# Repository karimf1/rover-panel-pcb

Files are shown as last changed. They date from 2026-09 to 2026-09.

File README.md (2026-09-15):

# rover-panel-pcb 

The PCB was missing. It sits on
four standoffs on the panel plate, between the shunt and the signal
connector, and does three jobs:

- **precharge** — it switches the pack through the panel's 22 Ω resistor `R1`
  into the ESC bank, and holds contactor `K1` open until the switched bus
  reaches ~90 % of the pack
- **interlock** — `K1`'s coil is energised through the E-stop loop *and* this
  board, so the board can open `K1` but nothing on it can close `K1` past an
  open E-stop
- **current sense** — an INA228 on the panel's 0.75 mΩ shunt `RS1`, reported
  over I2C

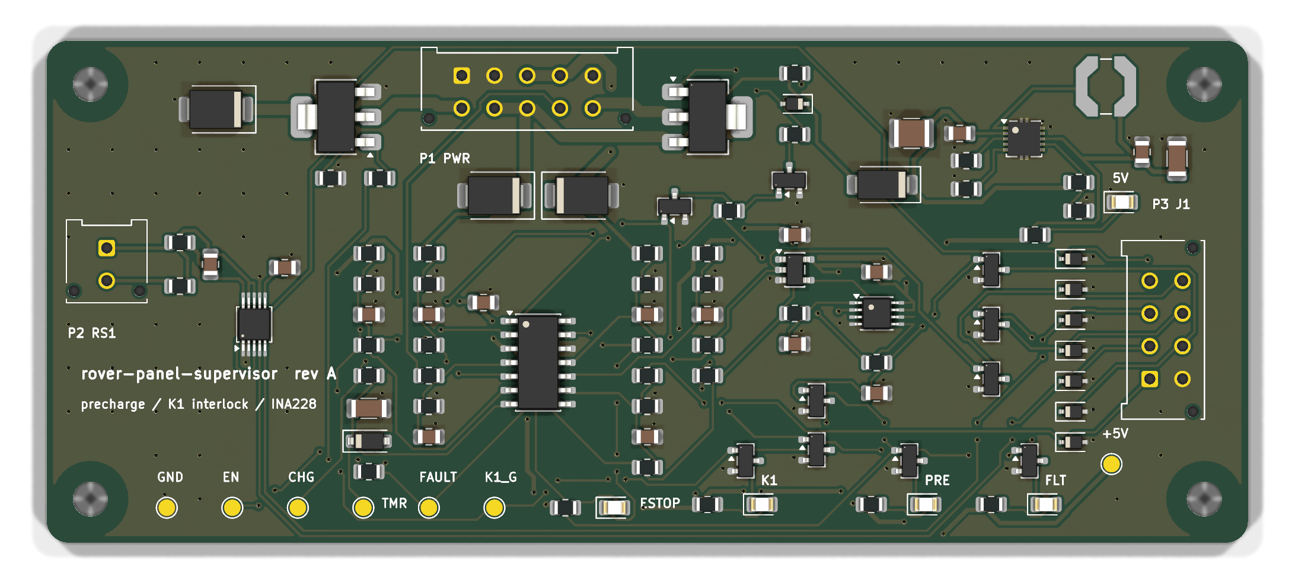
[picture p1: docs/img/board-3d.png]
Board


It replaces two of the panel's bought parts — `K2`, an automotive precharge
relay, and `A1`, an INA228 breakout on standoffs — and it answers two of the
panel's open questions: *"precharge is sized by hand and is not in any check"*
and *"is the E-stop hard-wired in series with the contactor coil?"*

The one claim the board is built to prove:

> **K1 cannot close unless the E-stop loop is closed AND the host has raised a
> fresh ARM edge AND the switched bus has reached the precharge threshold** —
> and that is hardware, checked against the exported netlist, not a promise
> made by firmware. There is no firmware.

---

## 1. How the interlock works

The logic is four comparators, one AND gate and one D flip-flop. Every node
that feeds the interlock is an open-collector output pulled up **to EN, not to
5 V** — so the instant the board disarms, every one of them falls with it.

| signal | made by | means |
|---|---|---|
| `ESTOP_OK` | U3C: the *far* side of the E-stop loop (`COIL_POS`) above 13.7 V | the mushroom switch is closed |
| `ARM` | U3D: host line above 1.37 V, 100 k pull-down | the host asked; an unplugged harness reads as *no* |
| `CLR#` | U4: `ARM AND ESTOP_OK` | either one dropping clears the latch immediately |
| `EN` | U5 (74LVC1G74) Q, set only on a **rising edge** of `ARM` delayed 10 ms | armed |
| `CHG` | U3A: switched bus / always-on bus **below** the threshold | precharging |
| `FAULT` | U3B: `CHG` has been high longer than the timer (≥ 1.68 s) | the bus is not charging — latches |
| `K1_G` | `EN`, pulled low by `CHG` (Q2) or `FAULT` (Q3), 1 ms RC | close the contactor |
| `PRE_G` | `EN`, pulled low by `FAULT` (Q4) | precharge switch on |

The flip-flop is there for one reason. With a plain AND gate, releasing the
E-stop while the host is still asserting `ARM` would re-energise the drive
motors on its own. With the latch, **an E-stop release does nothing until the
host drops `ARM` and raises it again.** That is what competition rules mean by
a deliberate restart, and it is scenario 5 in the simulation below.

The K1 coil path is:

```
+24 V -> P1.8 -> J1 -> E-stop -> J1 -> P1.3 -> P1.4 -> K1 coil -> P1.6 -> Q1 -> GND
```

`Q1` is on the low side. It can only *interrupt* that loop.

## 2. The design numbers

### Precharge threshold: a window, not a number

The comparator does not measure "90 % of 24 V". It compares two dividers —
the switched bus against the always-on bus — so it holds from a 21 V cutoff
to a 29.4 V full pack. Its threshold still moves, for three reasons, and
`calcs.pre_ratio_window()` takes every corner of all three:

- the hysteresis resistor injects a fixed 5 V into a divider of a *varying*
  pack, so the trip point shifts with pack voltage
- the four ratio resistors. They are 0.1 % parts because with 1 % parts the highest
  corner trips at 94.75 %, which is **above** the 94.50 % the bus can reach. The
  board would fault on a low pack.
- the LM339's 5 mV offset plus its 250 nA bias current through each divider

```
precharge threshold window     88.34 .. 91.74 % of pack
bus can reach through R1       94.50 % at 21 V, with 50 mA of ESC idle draw
```

**The ESC idle draw is the constraint.** The bus charges towards
`V − I_idle × R1`, not towards `V`. At a 21 V pack and 50 mA of idle current,
R1 takes 1.1 V off the target, and a threshold set at the textbook 95 % would
never be reached — the board would fault on every power-up. The 50 mA is
assumed and is the first thing to measure (§6).

### The fault timer has to outlast a slow precharge

```
precharge time, nominal        0.41 s    (6 mF, 25.9 V)
precharge time, worst          0.73 s    (9 mF, 21 V, highest threshold)
fault timer                    1.68 / 2.36 / 2.66 s   (min / nom / max)
```

The minimum assumes the 10 µF X7R timing capacitor has lost 25 % to tolerance
and DC bias, and that the comparator's full bias current is helping to charge
it. That still leaves 2.3× margin over the slowest legitimate precharge. The
maximum is bounded too: into a dead short, `R1` sees 41 W, inside its 50 W
continuous rating, for as long as the timer takes.

### The panel's supply budget

The panel's `params.py` reserves a supply for the board: a 2 A time-lag fuse on
`DIN2-203`, 18 AWG, 0.2 A continuous and a 2.5 A peak. The panel's
`sizing.py` sizes the wiring from those numbers, and this board checks that
its worst case fits inside them. Neither side can quietly outgrow the other.

```
24 V draw                      76 mA continuous (70 mA of it is K1's hold current)
                               2.17 A worst instant: K1 pull-in while precharge still conducts
```

### Everything else

| check | result |
|---|---|
| INA228 full scale at `ADCRANGE = 0` | 218 A, 0.42 mA per count, `SHUNT_CAL` = 2803 |
| current error at 10 A | 0.31 % (shunt 0.25 %, INA228 gain, offset, filter bias) |
| input TVS SM6T36A | stands off 30.8 V > 29.4 V; clamps 49.9 V < 60 V (every FET on the 24 V side) |
| K1 FET gate drive | 4.85 V on a 5 V −2 % rail, ≥ the 4.5 V its RDS(on) is quoted at |
| K1 coil at pack cutoff | 19.8 V ≥ 16 V pickup, after the E-stop loop, the FET and panel wiring |
| precharge FET gate | zener-clamped, ≤ 12.6 V worst case, from 21 V to 29.4 V (fully on, under ±20 V) |
| every LM339 input | inside `VCC − 1.5 V` at a full pack |
| power traces | 1.0 mm vs 0.70 mm IPC-2221 at 2.5 A as if continuous |

### The behaviour, simulated

`test_calcs.py` finishes with a 1 ms-step simulation of the interlock built
from those same thresholds and time constants — nothing retuned for the test:

```
PASS  power-up, ARM low: nothing switches
PASS  ARM with a healthy bus (3 mF): precharge, then K1, no fault  -- K1 closes 0.20 s after ARM, bus at 90.7 %
PASS  ARM with a healthy bus (9 mF): precharge, then K1, no fault  -- K1 closes 0.58 s after ARM, bus at 90.7 %
PASS  ARM into a shorted bus: FAULT latches, precharge stops, K1 never closes  -- fault 2.36 s after ARM
PASS  E-stop opens while K1 is closed: K1 drops within 1 ms
PASS  E-stop released with ARM still high: K1 stays OPEN (needs a new ARM edge)
PASS  ARM cycled after the E-stop reset: precharge and K1 again
PASS  FAULT holds for as long as ARM stays high (a latch, not a retry loop)
PASS  dropping ARM clears FAULT and leaves everything off
```

## 3. What changed from the plan

1. **It had no latch.** The plan's logic was `ARM AND E-STOP AND PRECHARGED`.
   Writing scenario 4 of the simulation showed what that does: release the
   E-stop with `ARM` still high and the motors come back on by themselves.
   The 74LVC1G74 and its 10 ms clock delay are the fix. KiCad 9 ships no
   74LVC1G74 symbol, so it is generated from a pin map in `spec.py`
   (`hw/gen/gen_lib.py`).
2. **The supply fuse is 2 A, not 1 A.** A 1 A fuse passes the board's 76 mA,
   but K1's 2 A pull-in comes through the same fuse.
3. **No 3.3 V rail.** The plan had an LDO for the INA228. Everything runs at
   5 V instead. The INA228's I2C thresholds do not follow its supply, and
   every output to the host is an open-drain FET, so this 5 V board never
   drives a 3.3 V pin. (That INA228 fact is one of the seven items flagged
   `VERIFY`.)
4. **The board is 110 × 46 mm, not ~90 × 55.** The panel set its height:
   25 mm of signal clearance to `K1` above and to the `DIN2` terminals below
   leaves 46 mm. Width was the only direction left to grow.
5. **The buck's pins are not in the 0.3 mm pack-voltage clearance class.** The
   LM5165's own pins are 0.22 mm apart. A 0.3 mm rule for them fails under the
   footprint itself, so the package sets that spacing.

## 4. The layout

Top copper

Placement is by hand, in `hw/gen/gen_pcb.py`, because placement *is* the
layout design:

- **P1** (power, coil, E-stop loop) is on the top edge, towards `K1` and `R1`.
  Its edge row is ground plus the E-stop-return/coil+ pair, which never has
  to leave the connector. Every net that travels is on the inner row.
- **P2** (the Kelvin pair) is on the left edge, facing `RS1`. The INA228 is
  turned so its inputs face P2 and its I2C and ground pins face open board.
- **P3** (signal to `J1`) is on the right edge, with the ESD diodes in a
  column in the same order as its pins.
- The coil FET and its clamps are left of P1, the precharge switch and buck
  are right of P1, the comparators are in the middle, and the LEDs are along
  the bottom edge where the hatch is.

The copper between the pads comes from `hw/gen/autoroute.py`: a 0.1 mm grid
A* router, two layers, that runs inside KiCad's own Python using numpy.

- Obstacles are painted at each net's own clearance class. The net being
  routed dilates the map by however much wider it is, so a 1 mm coil trace
  keeps 0.3 mm from everything, and a 0.2 mm signal can still leave a
  0.5 mm-pitch IC.
- Fine-pitch pads get straight escape stubs first, along their own axis.
- If a net cannot get out, it is **promoted** and the whole board re-routes
  from scratch with that net earlier in the queue. That is the cheapest
  rip-up-and-retry there is. The current layout routes on the first attempt
  in about 30 s.
- The ground pour is computed after routing, so a union-find walks every
  island, pad, via and track. Any ground pad the pour does not actually reach
  gets a real track to one it does. An island touching a via is not
  "connected" if that via lands in a fenced-off pocket on the other layer.

None of that is trusted. **kicad-cli DRC with schematic parity is the judge.**

```
802 track segments, 1753 mm of track (181 mm on B.Cu, the ground plane)
205 vias, all tented
0 DRC violations, 0 unconnected pads, 0 footprint errors
```

## 5. Verification

### The claim, against the netlist — `hw/gen/check_interlock.py`

This reads the netlist KiCad exported, not the generator, and checks the
structure the simulation assumes:

```
PASS  no on-board path from +24V_IN to COIL_POS, even with every FET on
PASS  COIL_POS touches only P1, a clamp to GND and a >= 100 k sense resistor  -- D6 TVS to ['GND'], R18 100k
PASS  the ONLY thing that can raise K1_G is one resistor from EN  -- pull-ups ['R29->EN']
PASS  K1_G is held low by precharge-in-progress (CHG) and by FAULT  -- Q2(gate CHG), Q3(gate FAULT)
PASS  EN is driven by U5.Q (pin 5) and nothing else
PASS  U5 D and /PRE are tied high: it can only SET on a clock edge
PASS  U5 /CLR = U4 output = ARM AND ESTOP_OK
PASS  VE is a divider off COIL_POS -- the FAR side of the E-stop loop
...                                                          24 checks
```

**And a test for the test.** A structural check that passes on a correct
netlist proves nothing unless it *fails* on a wrong one.
`test_interlock_check.py` applies six plausible mistakes to copies of the
netlist. It requires each one to be caught by the specific check written for
it:

```
PASS  a 100 ohm part bridging +24V_IN straight to the coil  -- caught by: no on-board path from +24V_IN to COIL_POS
PASS  K1_G pull-up taken from +5V instead of EN (E-stop and ARM bypassed)  -- caught by: the ONLY thing that can raise K1_G
PASS  E-stop sense divider moved to the pack side of the loop  -- caught by: VE is a divider off COIL_POS
PASS  flip-flop /CLR tied high (a released E-stop would re-arm by itself)  -- caught by: U5 /CLR = U4 output
PASS  precharge comparator reading the always-on bus twice  -- caught by: VA divides +24V_IN and VS divides SW_SENSE
PASS  FAULT no longer holds K1 off (Q3 gate moved to GND)  -- caught by: K1_G is held low by precharge-in-progress
```

### The layout rules DRC does not know — `hw/gen/check_layout.py`

A board can pass DRC with a 0.3 mm tap carrying the coil current. This script
checks the saved board:

- every power part on each coil, precharge and +24 V net is joined by copper
  at least 1.0 mm wide (union-find over wide tracks only)
- the Kelvin leads are length-matched: 5.3 vs 5.3 mm
- each TVS and decoupling capacitor sits within a stated distance of the pin
  it serves
- every ESD diode is within 15 mm of its P3 pin
- vias are tented
- at most 35 % of track length is on the ground-plane layer

On its first run it failed three times, and only one of those was the board:

1. **The board:** an ESD diode sat 18.5 mm from the P3 pin it protects.
2. **My classification:** reverse-polarity diode D2 was listed as a power
   part, but it only feeds the buck's few mA.
3. **The check itself:** it measured to the SOT-223's far drain pin instead
   of the tab.

Reviewing that output also turned up a problem the check had let through:
its 30 mm limit had let the coil+ clamp sit 28 mm from its pin. D6 now sits
under P1, and the limit is 12 mm.

### The board, measured twice — `hw/gen/check_fit.py`

The plate was drilled from the panel's `params.py`. The board was built from
`panel_interface.json`, which `params.py` wrote. This script reads the
**finished `.kicad_pcb`** back through pcbnew and compares it against
`params.py` imported live, so a stale JSON, a hand-edited board and a moved
plate hole all fail:

```
PASS  panel_interface.json is not stale (equals params.pcb_interface() now)
PASS  H1 at (4.00, 4.00) is where params.py put it  -- params (4, 4) dia 3.2, board dia 3.20
...
PASS  every board hole lands on a plate hole (panel frame)  -- plate [(236.0, 222.0), (236.0, 260.0), (338.0, 222.0), (338.0, 260.0)]
PASS  P1 sits on the top edge, facing its panel device  -- pads centred 4.7 mm from the top edge
PASS  P2 sits on the left edge, facing its panel device  -- pads centred 5.5 mm from the left edge
PASS  P3 sits on the right edge, facing its panel device  -- pads centred 7.5 mm from the right edge
PASS  standoff + board + tallest mated connector fits the height params.py allows  -- 10 + 1.6 + 25 = 36.6 mm <= 36.6 mm
```

## 6. Before ordering

1. K1's part number: its coil inrush, hold current and pickup voltage, and
   whether it has internal coil suppression. If it does not, add a
   TVS-limited freewheel path.
2. LM5165X: that the EN threshold is 1.2 V, RT to GND selects PFM, and ILIM
   to GND selects the low current limit. R3 and R4 are 0 Ω straps, so either
   choice can change without a respin.
3. LM5165X: that its VIN absolute maximum is 70 V.
4. L1: that its saturation current covers the PFM peak.
5. INA228: that its I2C thresholds are independent of VS.

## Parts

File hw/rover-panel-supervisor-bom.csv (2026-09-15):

Refs | Value | Footprint | MPN | Qty | DNP
C1 | 2u2 100V | Capacitor_SMD:C_1210_3225Metric |  | 1
C2 | 100n 100V | Capacitor_SMD:C_0805_2012Metric |  | 1
C3 | 22u 10V | Capacitor_SMD:C_1206_3216Metric |  | 1
C4-C8,C13-C18 | 100n 50V | Capacitor_SMD:C_0805_2012Metric |  | 11
C9,C10,C12 | 10n 50V | Capacitor_SMD:C_0805_2012Metric |  | 3
C11 | 10u 25V | Capacitor_SMD:C_1206_3216Metric |  | 1
D1,D5,D6 | SM6T36A | Diode_SMD:D_SMB | SM6T36A | 3
D2 | B160 | Diode_SMD:D_SMA | B160-13-F | 1
D3 | green 5V | LED_SMD:LED_0805_2012Metric |  | 1
D4 | 1N4148W | Diode_SMD:D_SOD-123 |  | 1
D7 | BZX384-C12 | Diode_SMD:D_SOD-323 | BZX384-C12 | 1
D8 | green K1 | LED_SMD:LED_0805_2012Metric |  | 1
D9 | amber PRECHARGE | LED_SMD:LED_0805_2012Metric |  | 1
D10 | red FAULT | LED_SMD:LED_0805_2012Metric |  | 1
D11 | red E-STOP OPEN | LED_SMD:LED_0805_2012Metric |  | 1
D12-D18 | PESD5V0S1BA | Diode_SMD:D_SOD-323 | PESD5V0S1BA | 7
L1 | 220uH | Inductor_SMD:L_Coilcraft_LPS5030 | Coilcraft LPS5030-224MRB | 1
P1 | P1 power/coil 2x05 | Connector_Molex:Molex_Micro-Fit_3.0_43045-1012_2x05_P3.00mm_Vertical | Molex 43045-1012 | 1
P2 | P2 Kelvin RS1 | Connector_Molex:Molex_Micro-Fit_3.0_43045-0212_2x01_P3.00mm_Vertical | Molex 43045-0212 | 1
P3 | P3 signal to J1 2x04 | Connector_Molex:Molex_Micro-Fit_3.0_43045-0812_2x04_P3.00mm_Vertical | Molex 43045-0812 | 1
Q1 | NDT3055L | Package_TO_SOT_SMD:SOT-223-3_TabPin2 | NDT3055L | 1
Q2-Q5,Q7-Q12 | 2N7002K | Package_TO_SOT_SMD:SOT-23 | 2N7002K | 10
Q6 | NDT2955 | Package_TO_SOT_SMD:SOT-223-3_TabPin2 | NDT2955 | 1
R1,R16,R20,R23,R31 | 1M | Resistor_SMD:R_0805_2012Metric |  | 5
R2 | 110k | Resistor_SMD:R_0805_2012Metric |  | 1
R3,R4 | 0R | Resistor_SMD:R_0805_2012Metric |  | 2
R5,R35-R38 | 1k5 | Resistor_SMD:R_0805_2012Metric |  | 5
R6,R7 | 10R | Resistor_SMD:R_0805_2012Metric |  | 2
R8 | 30k1 | Resistor_SMD:R_0805_2012Metric |  | 1
R9-R11,R19,R21,R24-R27,R29,R32,R33 | 10k | Resistor_SMD:R_0805_2012Metric |  | 12
R12,R14 | 100k 0.1% | Resistor_SMD:R_0805_2012Metric |  | 2
R13 | 9k76 0.1% | Resistor_SMD:R_0805_2012Metric |  | 1
R15 | 11k 0.1% | Resistor_SMD:R_0805_2012Metric |  | 1
R17 | 330k | Resistor_SMD:R_0805_2012Metric |  | 1
R18,R22,R28 | 100k | Resistor_SMD:R_0805_2012Metric |  | 3
R30 | 100R | Resistor_SMD:R_0805_2012Metric |  | 1
R34 | 47k | Resistor_SMD:R_0805_2012Metric |  | 1
U1 | LM5165X | Package_SON:Texas_S-PVSON-N10_ThermalVias | LM5165XDRCR | 1
U2 | INA228 | Package_SO:VSSOP-10_3x3mm_P0.5mm | INA228AIDGSR | 1
U3 | LM339 | Package_SO:SOIC-14_3.9x8.7mm_P1.27mm | LM339DR | 1
U4 | 74LVC1G08 | Package_TO_SOT_SMD:SOT-23-5 | SN74LVC1G08DBVR | 1
U5 | SN74LVC1G74 | Package_SO:SSOP-8_2.95x2.8mm_P0.65mm |  | 1

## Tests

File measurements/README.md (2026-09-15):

# Measurements — template, nothing measured yet

Every number in the project README is a calculation. This is where the
measurements that replace them go, one table per test, with the scope
captures beside them.

## Bench setup

| item | value |
|---|---|
| supply | bench PSU at 21.0 V, 25.9 V and 29.4 V (7S cutoff, nominal, full) |
| switched bus | capacitor bank standing in for the ESCs: 3 mF and 9 mF |
| ESC idle draw | electronic load in CC mode on the bus: 0, 50 and 100 mA |
| K1 | the real contactor, or a 24 V relay coil of similar inrush |
| R1 | the panel's 22 R 50 W resistor |
| probes | CH1 bus, CH2 `CHG` (TP4), CH3 `TMR` (TP5), CH4 `K1_G` (TP7) |

## 1. Precharge threshold

The prediction is 88.3–91.7 % of pack, from `calcs.pre_ratio_window()`.

| pack V | idle mA | bus V when `CHG` falls | ratio | predicted |
|---|---|---|---|---|
| 21.0 | 50 | | | 88.3 – 91.7 % |
| 25.9 | 50 | | | |
| 29.4 | 50 | | | |
| 21.0 | 100 | | | must still reach the threshold |

## 2. Precharge time and fault timer

| bus C | pack V | ARM -> K1_G high (s) | predicted | shorted bus: ARM -> FAULT (s) | predicted |
|---|---|---|---|---|---|
| 3 mF | 25.9 | | 0.20 (simulated) | | 1.68 – 2.66 |
| 9 mF | 21.0 | | 0.73 worst | | |

## 3. Interlock scenarios (pass / fail)

| # | scenario | expected | result |
|---|---|---|---|
| 1 | power up with ARM low | nothing switches | |
| 2 | ARM, healthy bus | precharge, then K1 | |
| 3 | ARM into a shorted bus | FAULT latches, K1 never closes | |
| 4 | open E-stop with K1 closed | K1 drops | |
| 5 | release E-stop, ARM still high | K1 stays open | |
| 6 | cycle ARM after 5 | precharge and K1 again | |
| 7 | drop ARM during FAULT | FAULT clears after ~1.7 s | |

## 4. INA228 against a reference meter

| load A | reference A | INA228 A | error % | predicted |
|---|---|---|---|---|
| 1 | | | | |
| 10 | | | | < 0.31 % |
| 50 | | | | |

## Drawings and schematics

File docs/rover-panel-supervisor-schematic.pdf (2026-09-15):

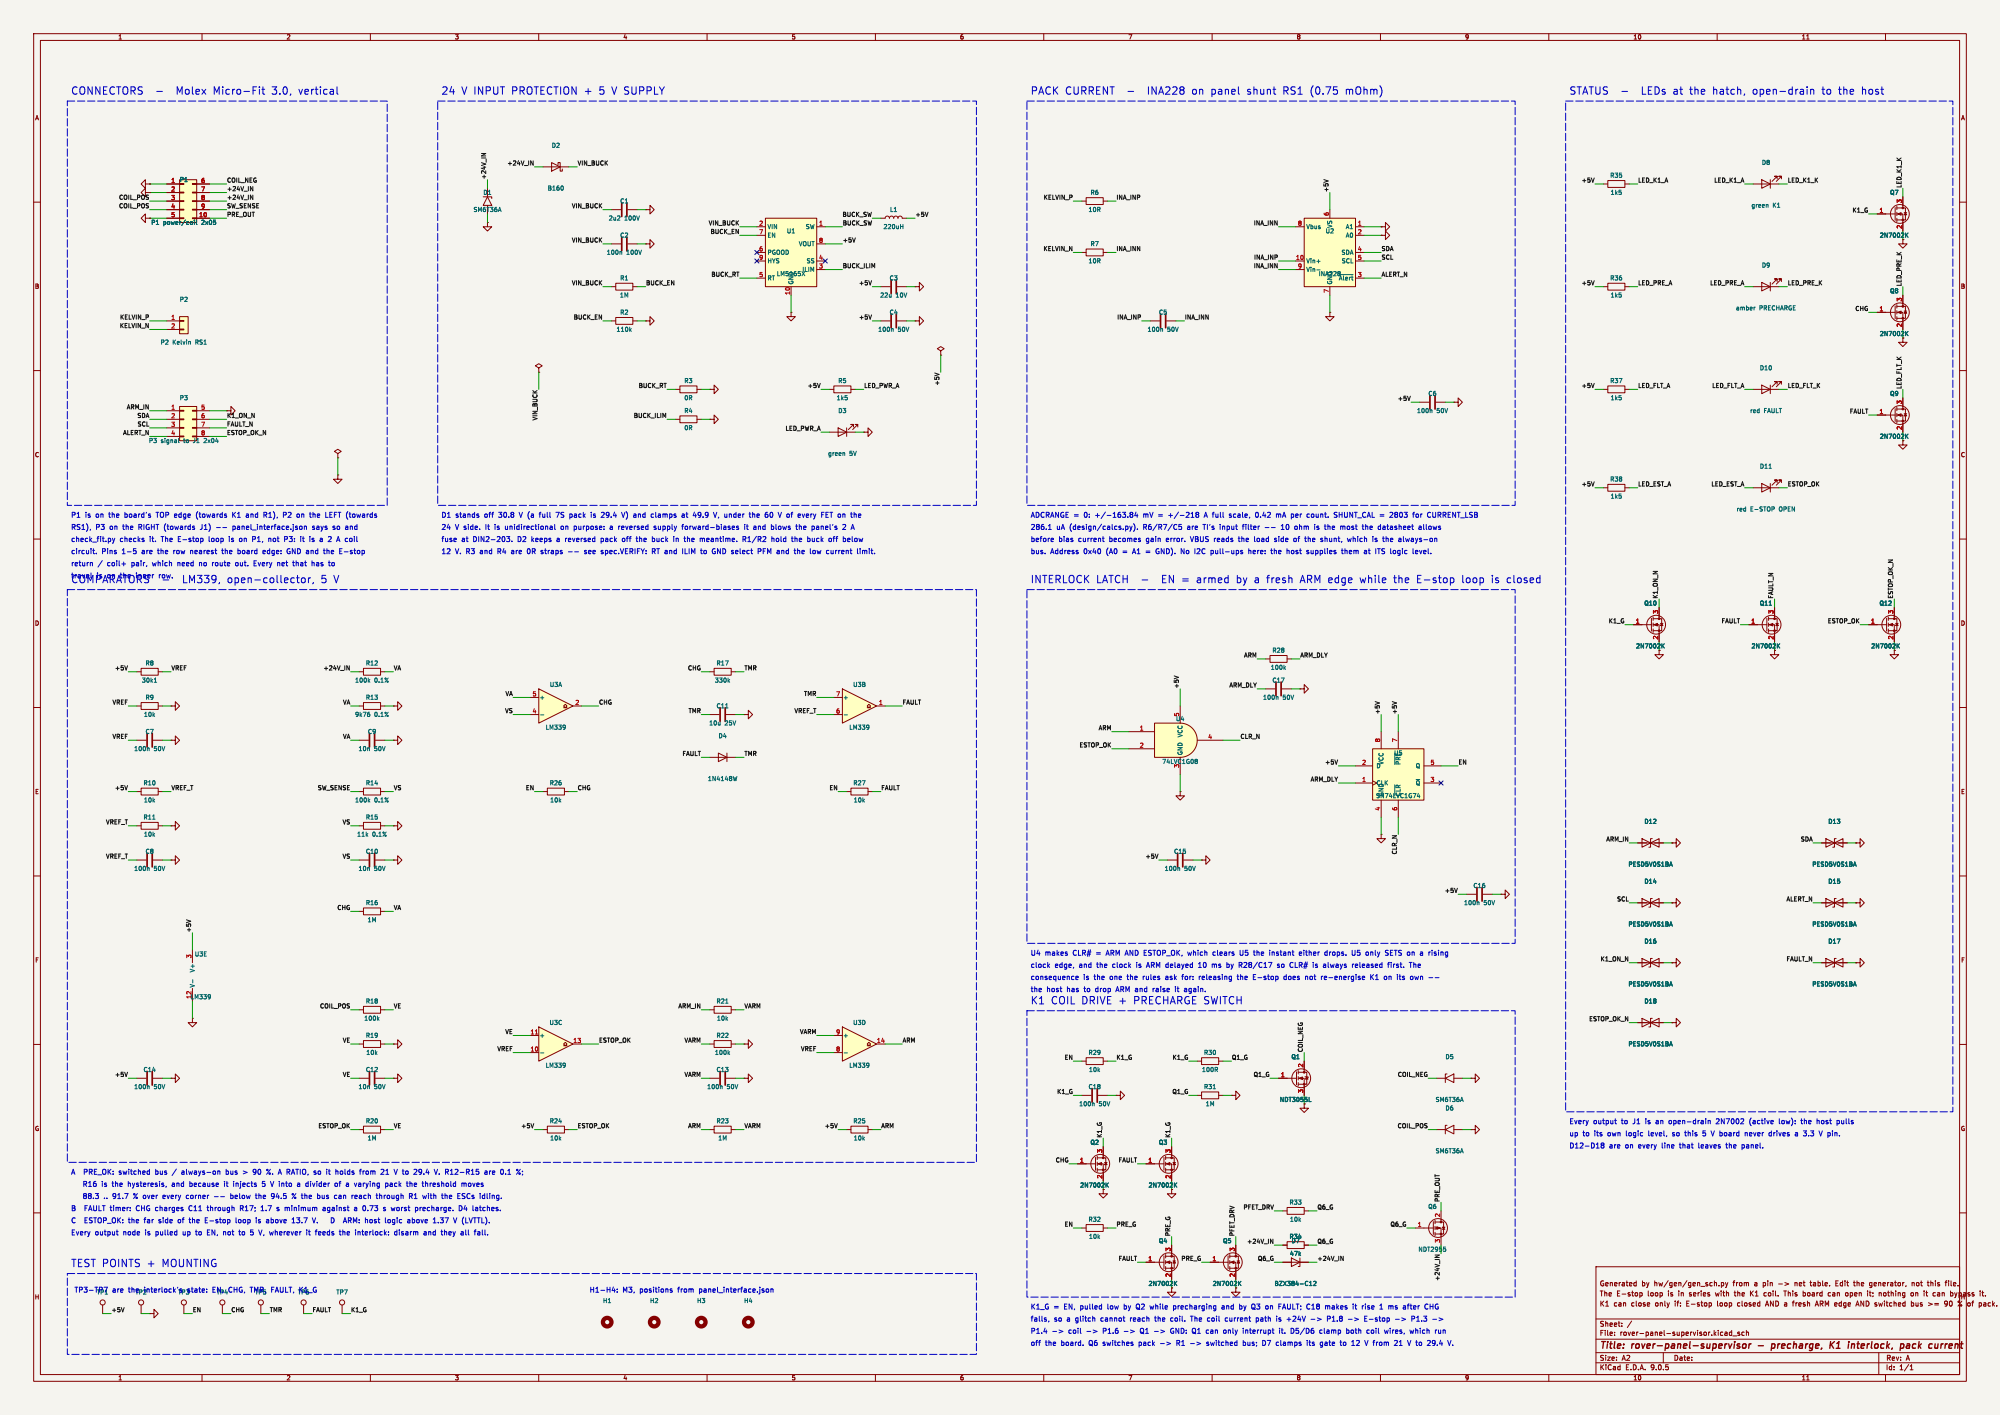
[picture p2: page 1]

travel is on the inner row.

D1 stands off 30.8 V (a full 7S pack is 29.4 V) and clamps at 49.9 V, under the 60 V of every FET on the

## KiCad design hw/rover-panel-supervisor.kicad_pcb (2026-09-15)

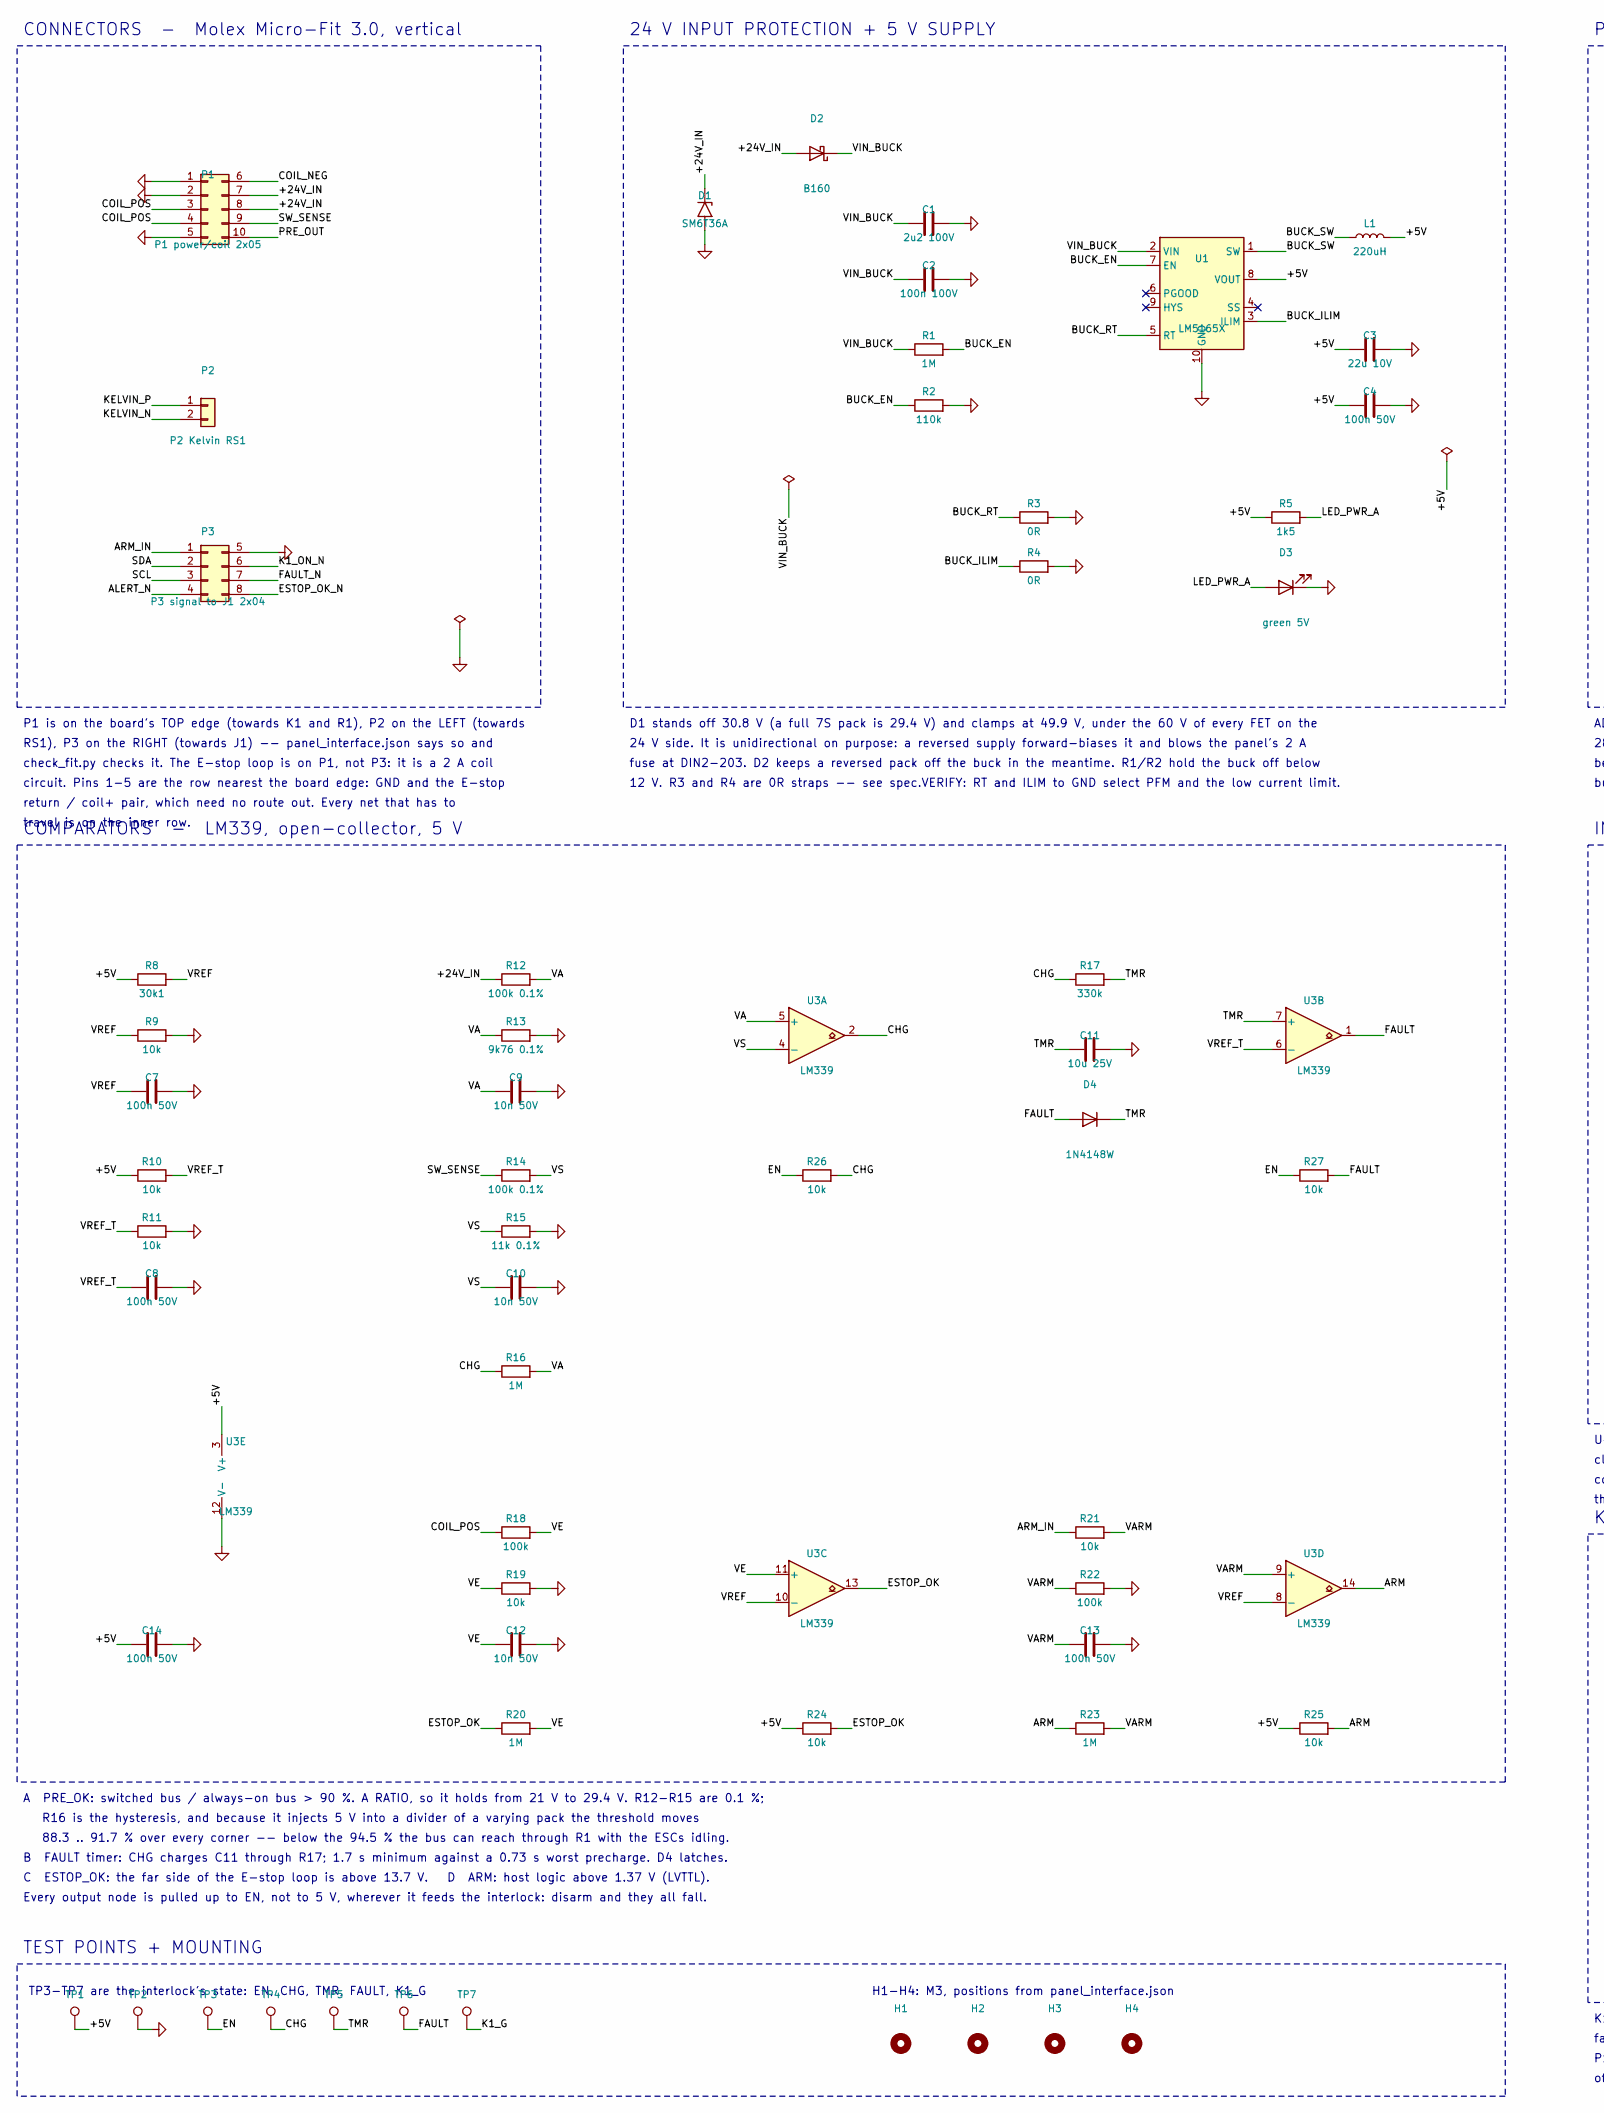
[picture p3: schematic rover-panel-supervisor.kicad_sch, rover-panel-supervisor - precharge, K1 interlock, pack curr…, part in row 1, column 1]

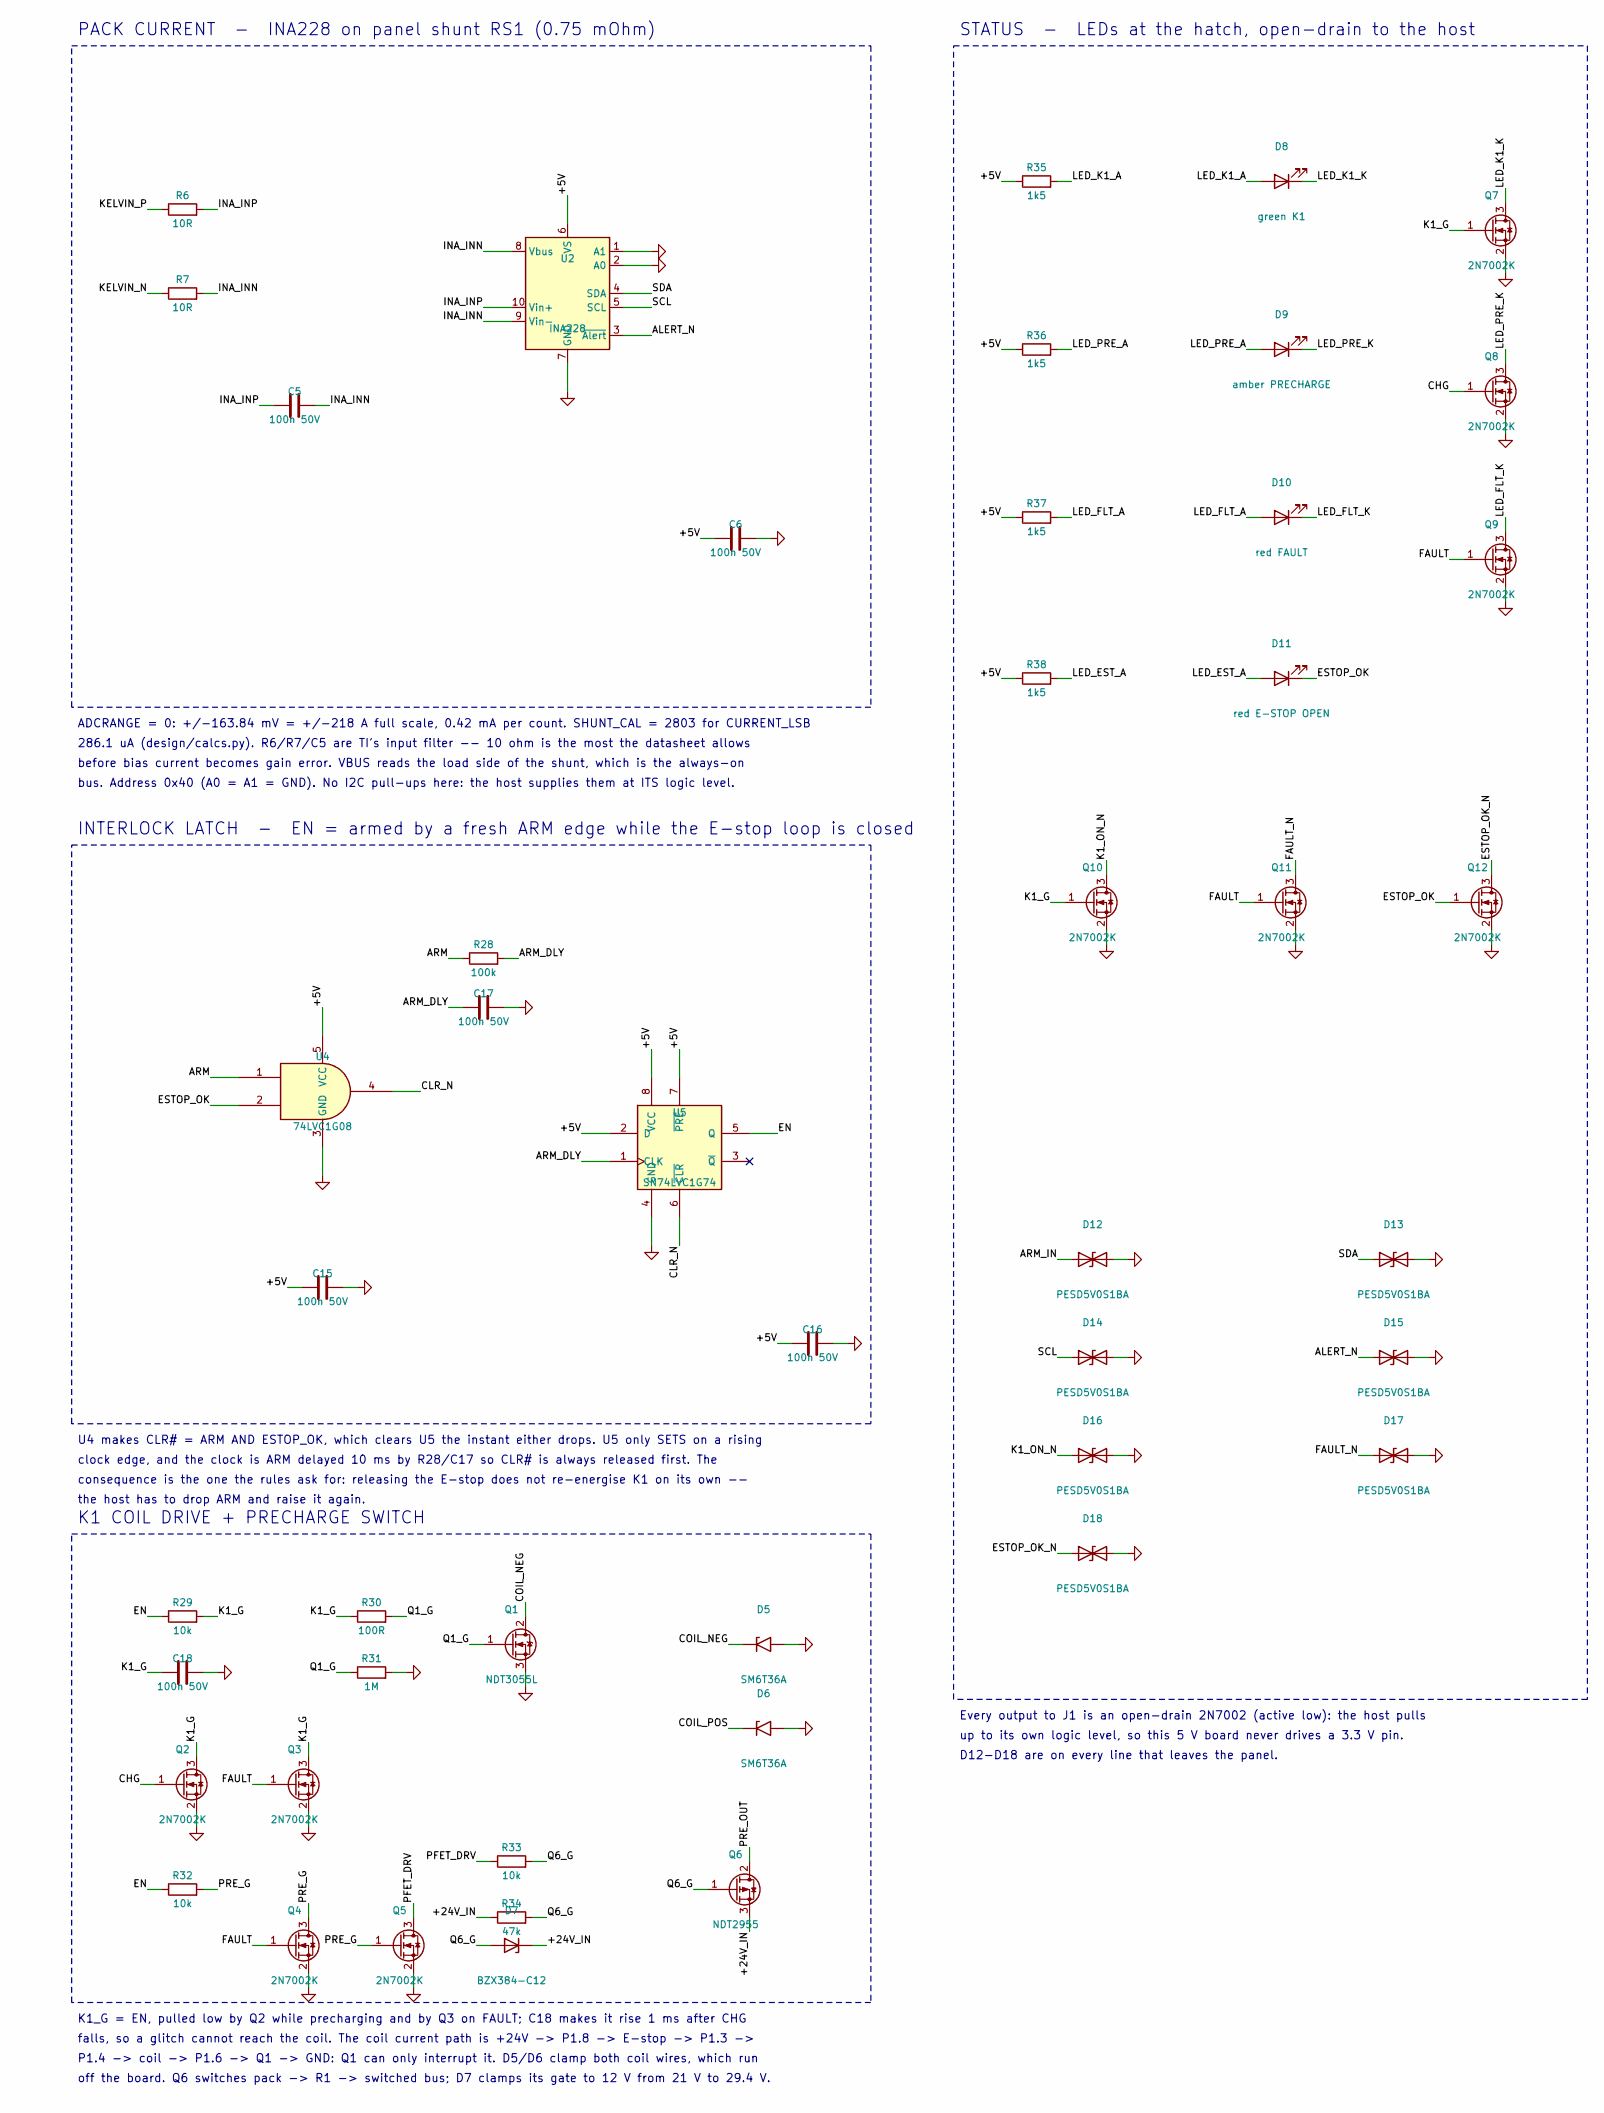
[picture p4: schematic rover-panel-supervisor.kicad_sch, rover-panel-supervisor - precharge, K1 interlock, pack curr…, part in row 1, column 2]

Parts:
C1: 2u2 100V; C_1210_3225Metric; Voltage 100 V
C2: 100n 100V; C_0805_2012Metric; Voltage 100 V
C3: 22u 10V; C_1206_3216Metric; Voltage 10 V
C4, C5, C6, C7, C8, C13, C14, C15, C16, C17, C18: 100n 50V; C_0805_2012Metric; Voltage 50 V
C9, C10, C12: 10n 50V; C_0805_2012Metric; Voltage 50 V
C11: 10u 25V; C_1206_3216Metric; Voltage 25 V
D1: SM6T36A; D_SMB; MPN SM6T36A
D2: B160; D_SMA; MPN B160-13-F
D3: green 5V; LED_0805_2012Metric
D4: 1N4148W; D_SOD-123
D5, D6: SM6T36A; D_SMB
D7: BZX384-C12; D_SOD-323; MPN BZX384-C12
D8: green K1; LED_0805_2012Metric
D9: amber PRECHARGE; LED_0805_2012Metric
D10: red FAULT; LED_0805_2012Metric
D11: red E-STOP OPEN; LED_0805_2012Metric
D12, D13, D14, D15, D16, D17, D18: PESD5V0S1BA; D_SOD-323; MPN PESD5V0S1BA
H1, H2, H3, H4: M3; MountingHole_3.2mm_M3
L1: 220uH; L_Coilcraft_LPS5030; MPN Coilcraft LPS5030-224MRB
P1: P1 power/coil 2x05; Molex_Micro-Fit_3.0_43045-1012_2x05_P3.00mm_Vertical; MPN Molex 43045-1012
P2: P2 Kelvin RS1; Molex_Micro-Fit_3.0_43045-0212_2x01_P3.00mm_Vertical; MPN Molex 43045-0212
P3: P3 signal to J1 2x04; Molex_Micro-Fit_3.0_43045-0812_2x04_P3.00mm_Vertical; MPN Molex 43045-0812
Q1: NDT3055L; SOT-223-3_TabPin2; MPN NDT3055L
Q2, Q3, Q4, Q5, Q7, Q8, Q9, Q10, Q11, Q12: 2N7002K; SOT-23; MPN 2N7002K
Q6: NDT2955; SOT-223-3_TabPin2; MPN NDT2955
R1, R16, R20, R23, R31: 1M; R_0805_2012Metric
R2: 110k; R_0805_2012Metric
R3, R4: 0R; R_0805_2012Metric
R5, R35, R36, R37, R38: 1k5; R_0805_2012Metric
R6, R7: 10R; R_0805_2012Metric
R8: 30k1; R_0805_2012Metric
R9, R10, R11, R19, R21, R24, R25, R26, R27, R29, R32, R33: 10k; R_0805_2012Metric
R12, R14: 100k 0.1%; R_0805_2012Metric; Tolerance 0.1%
R13: 9k76 0.1%; R_0805_2012Metric; Tolerance 0.1%
R15: 11k 0.1%; R_0805_2012Metric; Tolerance 0.1%
R17: 330k; R_0805_2012Metric
R18, R22, R28: 100k; R_0805_2012Metric
R30: 100R; R_0805_2012Metric
R34: 47k; R_0805_2012Metric
TP1: +5V; TestPoint_Pad_D1.5mm
TP2: GND; TestPoint_Pad_D1.5mm
TP3: EN; TestPoint_Pad_D1.5mm
TP4: CHG; TestPoint_Pad_D1.5mm
TP5: TMR; TestPoint_Pad_D1.5mm
TP6: FAULT; TestPoint_Pad_D1.5mm
TP7: K1_G; TestPoint_Pad_D1.5mm
U1: LM5165X; Texas_S-PVSON-N10_ThermalVias; MPN LM5165XDRCR
U2: INA228; VSSOP-10_3x3mm_P0.5mm; MPN INA228AIDGSR
U3: LM339; SOIC-14_3.9x8.7mm_P1.27mm; MPN LM339DR
U4: 74LVC1G08; SOT-23-5; MPN SN74LVC1G08DBVR
U5: SN74LVC1G74; SSOP-8_2.95x2.8mm_P0.65mm

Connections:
/+5V: C3.1, C4.1, C6.1, C14.1, C15.1, C16.1, L1.2, R5.1, R8.1, R10.1, R24.1, R25.1, R35.1, R36.1, R37.1, R38.1, TP1.1, U1.8 (VOUT), U2.6 (VS), U3.3 (V+), U4.5 (VCC), U5.2 (D), U5.7 (~PRE), U5.8 (VCC)
/+24V_IN: D1.1 (A1), D2.2 (A), D7.1 (K), P1.7, P1.8, Q6.3 (S), R12.1, R34.1
/ALERT_N: D15.1 (A1), P3.4, U2.3 (~Alert)
/ARM: R23.1, R25.2, R28.1, U3.14, U4.1
/ARM_DLY: C17.1, R28.2, U5.1 (CLK)
/ARM_IN: D12.1 (A1), P3.1, R21.1
/BUCK_EN: R1.2, R2.1, U1.7 (EN)
/BUCK_ILIM: R4.1, U1.3 (ILIM)
/BUCK_RT: R3.1, U1.5 (RT)
/BUCK_SW: L1.1, U1.1 (SW)
/CHG: Q2.1 (G), Q8.1 (G), R16.1, R17.1, R26.2, TP4.1, U3.2
/CLR_N: U4.4, U5.6 (~CLR)
/COIL_NEG: D5.1 (A1), P1.6, Q1.2 (D)
/COIL_POS: D6.1 (A1), P1.3, P1.4, R18.1
/EN: R26.1, R27.1, R29.1, R32.1, TP3.1, U5.5 (Q)
/ESTOP_OK: D11.1 (K), Q12.1 (G), R20.1, R24.2, U3.13, U4.2
/ESTOP_OK_N: D18.1 (A1), P3.8, Q12.3 (D)
/FAULT: D4.2 (A), Q3.1 (G), Q4.1 (G), Q9.1 (G), Q11.1 (G), R27.2, TP6.1, U3.1
/FAULT_N: D17.1 (A1), P3.7, Q11.3 (D)
/INA_INN: C5.2, R7.2, U2.8 (Vbus), U2.9 (Vin-)
/INA_INP: C5.1, R6.2, U2.10 (Vin+)
/K1_G: C18.1, Q2.3 (D), Q3.3 (D), Q7.1 (G), Q10.1 (G), R29.2, R30.1, TP7.1
/K1_ON_N: D16.1 (A1), P3.6, Q10.3 (D)
/KELVIN_N: P2.2, R7.1
/KELVIN_P: P2.1, R6.1
/LED_EST_A: D11.2 (A), R38.2
/LED_FLT_A: D10.2 (A), R37.2
/LED_FLT_K: D10.1 (K), Q9.3 (D)
/LED_K1_A: D8.2 (A), R35.2
/LED_K1_K: D8.1 (K), Q7.3 (D)
/LED_PRE_A: D9.2 (A), R36.2
/LED_PRE_K: D9.1 (K), Q8.3 (D)
/LED_PWR_A: D3.2 (A), R5.2
/PFET_DRV: Q5.3 (D), R33.1
/PRE_G: Q4.3 (D), Q5.1 (G), R32.2
/PRE_OUT: P1.10, Q6.2 (D)
/Q1_G: Q1.1 (G), R30.2, R31.1
/Q6_G: D7.2 (A), Q6.1 (G), R33.2, R34.2
/SCL: D14.1 (A1), P3.3, U2.5 (SCL)
/SDA: D13.1 (A1), P3.2, U2.4 (SDA)
/SW_SENSE: P1.9, R14.1
/TMR: C11.1, D4.1 (K), R17.2, TP5.1, U3.7 (+)
/VA: C9.1, R12.2, R13.1, R16.2, U3.5 (+)
/VARM: C13.1, R21.2, R22.1, R23.2, U3.9 (+)
/VE: C12.1, R18.2, R19.1, R20.2, U3.11 (+)
/VIN_BUCK: C1.1, C2.1, D2.1 (K), R1.1, U1.2 (VIN)
/VREF: C7.1, R8.2, R9.1, U3.8 (-), U3.10 (-)
/VREF_T: C8.1, R10.2, R11.1, U3.6 (-)
/VS: C10.1, R14.2, R15.1, U3.4 (-)
GND: C1.2, C2.2, C3.2, C4.2, C6.2, C7.2, C8.2, C9.2, C10.2, C11.2, C12.2, C13.2, C14.2, C15.2, C16.2, C17.2, C18.2, D1.2 (A2), D3.1 (K), D5.2 (A2), D6.2 (A2), D12.2 (A2), D13.2 (A2), D14.2 (A2), D15.2 (A2), D16.2 (A2), D17.2 (A2), D18.2 (A2), P1.1, P1.2, P1.5, P3.5, Q1.3 (S), Q2.2 (S), Q3.2 (S), Q4.2 (S), Q5.2 (S), Q7.2 (S), Q8.2 (S), Q9.2 (S), Q10.2 (S), Q11.2 (S), Q12.2 (S), R2.2, R3.2, R4.2, R9.2, R11.2, R13.2, R15.2, R19.2, R22.2, R31.2, TP2.1, U1.10 (GND), U1.11 (GND), U2.1 (A1), U2.2 (A0), U2.7 (GND), U3.12 (V-), U4.3 (GND), U5.4 (GND)

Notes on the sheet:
CONNECTORS - Molex Micro-Fit 3.0, vertical
P1 is on the board's TOP edge (towards K1 and R1), P2 on the LEFT (towards
RS1), P3 on the RIGHT (towards J1) -- panel_interface.json says so and
check_fit.py checks it. The E-stop loop is on P1, not P3: it is a 2 A coil
circuit. Pins 1-5 are the row nearest the board edge: GND and the E-stop
return / coil+ pair, which need no route out. Every net that has to
travel is on the inner row.
24 V INPUT PROTECTION + 5 V SUPPLY
D1 stands off 30.8 V (a full 7S pack is 29.4 V) and clamps at 49.9 V, under the 60 V of every FET on the
24 V side. It is unidirectional on purpose: a reversed supply forward-biases it and blows the panel's 2 A
fuse at DIN2-203. D2 keeps a reversed pack off the buck in the meantime. R1/R2 hold the buck off below
12 V. R3 and R4 are 0R straps -- see spec.VERIFY: RT and ILIM to GND select PFM and the low current limit.
PACK CURRENT - INA228 on panel shunt RS1 (0.75 mOhm)
ADCRANGE = 0: +/-163.84 mV = +/-218 A full scale, 0.42 mA per count. SHUNT_CAL = 2803 for CURRENT_LSB
286.1 uA (design/calcs.py). R6/R7/C5 are TI's input filter -- 10 ohm is the most the datasheet allows
before bias current becomes gain error. VBUS reads the load side of the shunt, which is the always-on
bus. Address 0x40 (A0 = A1 = GND). No I2C pull-ups here: the host supplies them at ITS logic level.
COMPARATORS - LM339, open-collector, 5 V
A PRE_OK: switched bus / always-on bus > 90 %. A RATIO, so it holds from 21 V to 29.4 V. R12-R15 are 0.1 %;
R16 is the hysteresis, and because it injects 5 V into a divider of a varying pack the threshold moves
88.3 .. 91.7 % over every corner -- below the 94.5 % the bus can reach through R1 with the ESCs idling.
B FAULT timer: CHG charges C11 through R17; 1.7 s minimum against a 0.73 s worst precharge. D4 latches.
C ESTOP_OK: the far side of the E-stop loop is above 13.7 V. D ARM: host logic above 1.37 V (LVTTL).
Every output node is pulled up to EN, not to 5 V, wherever it feeds the interlock: disarm and they all fall.
INTERLOCK LATCH - EN = armed by a fresh ARM edge while the E-stop loop is closed
U4 makes CLR# = ARM AND ESTOP_OK, which clears U5 the instant either drops. U5 only SETS on a rising
clock edge, and the clock is ARM delayed 10 ms by R28/C17 so CLR# is always released first. The
consequence is the one the rules ask for: releasing the E-stop does not re-energise K1 on its own --
the host has to drop ARM and raise it again.
K1 COIL DRIVE + PRECHARGE SWITCH
K1_G = EN, pulled low by Q2 while precharging and by Q3 on FAULT; C18 makes it rise 1 ms after CHG
falls, so a glitch cannot reach the coil. The coil current path is +24V -> P1.8 -> E-stop -> P1.3 ->
P1.4 -> coil -> P1.6 -> Q1 -> GND: Q1 can only interrupt it. D5/D6 clamp both coil wires, which run
off the board. Q6 switches pack -> R1 -> switched bus; D7 clamps its gate to 12 V from 21 V to 29.4 V.
STATUS - LEDs at the hatch, open-drain to the host
Every output to J1 is an open-drain 2N7002 (active low): the host pulls
up to its own logic level, so this 5 V board never drives a 3.3 V pin.
D12-D18 are on every line that leaves the panel.
TEST POINTS + MOUNTING
TP3-TP7 are the interlock's state: EN, CHG, TMR, FAULT, K1_G

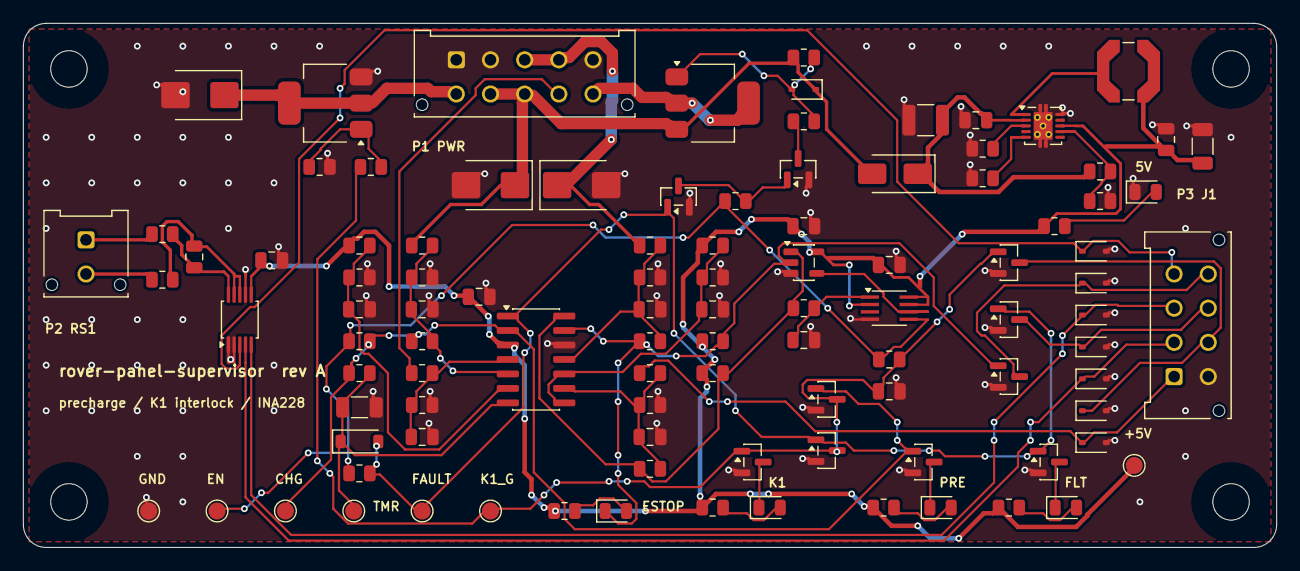
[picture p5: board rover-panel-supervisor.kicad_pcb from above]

Board: 2 copper layers, 110.0 x 46.0 mm, 106 parts (0 on the bottom side), 50 nets.

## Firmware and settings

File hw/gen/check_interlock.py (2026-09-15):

#!/usr/bin/env python3
"""The board's one claim, checked against the netlist KiCad exported.

    K1 cannot close unless the E-stop loop is closed AND the host has raised a
    fresh ARM edge AND the switched bus has reached the precharge threshold.

design/test_calcs.py simulates that behaviour from the thresholds. This script
checks the STRUCTURE that the simulation assumes: that the copper really is
wired the way the simulation says, so that no part on the board -- through a
wrong net, a swapped pin, a stray resistor -- can energise the coil any other
way. It reads rover-panel-supervisor.net, not the generator, so it checks what
KiCad will build rather than what the generator meant.

Every check names the specific parts it is about. Exit status 0 only if all pass.
"""
import os
import re
import sys

HERE = os.path.dirname(os.path.abspath(__file__))
NET = sys.argv[1] if len(sys.argv) > 1 else os.path.join(HERE, "..", "rover-panel-supervisor.net")

FAILED = []


def check(name, ok, detail=""):
    print(f"  {'PASS' if ok else 'FAIL'}  {name}{('  -- ' + detail) if detail else ''}")
    if not ok:
        FAILED.append(name)


# ------------------------------------------------------------------ netlist
text = open(NET).read()
COMP = {}
for m in re.finditer(r'\(comp \(ref "([^"]+)"\)\s*\(value "([^"]*)"\)[\s\S]*?'
                     r'\(libsource \(lib "([^"]*)"\) \(part "([^"]*)"\)', text):
    COMP[m.group(1)] = dict(value=m.group(2), lib=m.group(3), part=m.group(4))
NETS = {}
PIN = {}                       # (ref, pin) -> net
for m in re.finditer(r'\(net \(code "\d+"\) \(name "([^"]*)"\)[^\n]*\n((?:\s+\(node[^\n]*\n?)*)',
                     text[text.index("(nets"):]):
    name = m.group(1).lstrip("/")
    nodes = re.findall(r'\(ref "([^"]+)"\) \(pin "([^"]+)"\)', m.group(2))
    NETS[name] = nodes
    for r, p in nodes:
        PIN[(r, p)] = name


def ohms(v):
    """'9k76 0.1%' -> 9760.0; None if it is not a resistance."""
    m = re.match(r"^(\d+)([RkM])(\d*)", v)
    if not m:
        return None
    mult = {"R": 1, "k": 1e3, "M": 1e6}[m.group(2)]
    return float(f"{m.group(1)}.{m.group(3) or 0}") * mult


def on(net):
    return NETS.get(net, [])


def kind(ref):
    p = COMP[ref]["part"]
    if ref.startswith("R"):
        return "R"
    if ref.startswith("C"):
        return "C"
    if ref.startswith("TP"):
        return "TP"
    if ref.startswith("P"):
        return "CONN"
    if p in ("2N7002", "NDT3055L"):
        return "NFET"
    if p == "Q_PMOS_GDS":
        return "PFET"
    if p.startswith("SM6T") or p == "D_TVS":
        return "TVS"
    if ref.startswith("D"):
        return "D"
    if ref.startswith("L"):
        return "L"
    return "IC"


# FET pins: 2N7002 is G=1 S=2 D=3; NDT3055L and Q_PMOS_GDS are G=1 D=2 S=3
def fet_pins(ref):
    if COMP[ref]["part"] == "2N7002":
        return {"G": "1", "S": "2", "D": "3"}
    return {"G": "1", "D": "2", "S": "3"}


print("== interlock: structural checks on the exported netlist ==")
print(f"  {len(COMP)} parts, {len(NETS)} nets")

# --------------------------------------------------- 1. the E-stop loop is the
# only way pack voltage reaches the coil's positive side
LOW_OHM = 1000.0


def conducting_neighbours(net):
    """Nets reachable from `net` through one part that could carry coil current:
    a resistor under 1 k, an inductor, any diode forward or zener, and EVERY
    FET channel as if it were switched on. TVS parts count as open -- they
    stand off above a full pack, which spec.py checks."""
    out = set()
    for ref, pin in on(net):
        k = kind(ref)
        pins = [p for (r, p) in PIN if r == ref]
        others = {PIN[(ref, p)] for p in pins if p != pin}
        if k == "R" and (ohms(COMP[ref]["value"]) or 0) < LOW_OHM:
            out |= others
        elif k in ("L", "D"):
            out |= others
        elif k in ("NFET", "PFET"):
            fp = fet_pins(ref)
            if pin in (fp["D"], fp["S"]):
                out.add(PIN[(ref, fp["S"] if pin == fp["D"] else fp["D"])])
    return out


seen, todo = {"+24V_IN"}, ["+24V_IN"]
while todo:
    n = todo.pop()
    for m in conducting_neighbours(n):
        if m not in seen and m != "GND":
            seen.add(m)
            todo.append(m)
check("no on-board path from +24V_IN to COIL_POS, even with every FET on",
      "COIL_POS" not in seen,
      f"+24V_IN reaches {len(seen)} nets through low-impedance parts; COIL_POS is not one")

coil_pos_parts = sorted({r for r, _ in on("COIL_POS")})
ok = True
why = []
for r in coil_pos_parts:
    k = kind(r)
    if k == "CONN":
        continue
    if k == "TVS":
        other = [PIN[(r, p)] for (rr, p) in PIN if rr == r and PIN[(rr, p)] != "COIL_POS"]
        ok &= other == ["GND"]
        why.append(f"{r} TVS to {other}")
    elif k == "R":
        ok &= (ohms(COMP[r]["value"]) or 0) >= 100e3
        why.append(f"{r} {COMP[r]['value']}")
    else:
        ok = False
        why.append(f"{r} UNEXPECTED")
check("COIL_POS touches only P1, a clamp to GND and a >= 100 k sense resistor",
      ok, ", ".join(why))
check("COIL_POS arrives on two P1 pins: E-stop return in, coil + out",
      sorted(p for r, p in on("COIL_POS") if r == "P1") == ["3", "4"])
check("the E-stop loop source is +24V_IN on P1.8",
      PIN.get(("P1", "8")) == "+24V_IN")

# ------------------------------------------------ 2. the coil's low side
cn = sorted(on("COIL_NEG"))
q1 = fet_pins("Q1")
check("COIL_NEG goes only to P1.6, Q1's drain and a clamp",
      set(cn) == {("P1", "6"), ("Q1", q1["D"]), ("D5", "1")}, str(cn))
check("Q1's source is GND", PIN[("Q1", q1["S"])] == "GND")
check("Q1's gate is driven only through R30 from K1_G (R31 pulls it down)",
      sorted(r for r, _ in on(PIN[("Q1", q1["G"])])) == ["Q1", "R30", "R31"]
      and {PIN[("R30", "1")], PIN[("R30", "2")]} == {"K1_G", "Q1_G"}
      and {PIN[("R31", "1")], PIN[("R31", "2")]} == {"Q1_G", "GND"})

# ------------------------------------------------ 3. what can pull K1_G high
pullers, holders, loads = [], [], []
for r, p in on("K1_G"):
    k = kind(r)
    if k == "R":
        other = PIN[(r, "2" if p == "1" else "1")]
        (pullers if other not in ("GND", "Q1_G") else loads).append(f"{r}->{other}")
    elif k == "NFET":
        fp = fet_pins(r)
        if p == fp["D"]:
            assert PIN[(r, fp["S"])] == "GND", r
            holders.append(f"{r}(gate {PIN[(r, fp['G'])]})")
        else:
            loads.append(f"{r} gate")
    elif k in ("C", "TP"):
        loads.append(r)
    else:
        pullers.append(f"{r} UNEXPECTED")
check("the ONLY thing that can raise K1_G is one resistor from EN",
      pullers == ["R29->EN"], f"pull-ups {pullers}")
check("K1_G is held low by precharge-in-progress (CHG) and by FAULT",
      sorted(h.split("gate ")[1].rstrip(")") for h in holders) == ["CHG", "FAULT"],
      ", ".join(holders))
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

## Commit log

2026-09-15 Remove testing instructions from README
    Removed instructions for testing with boards and measurements.
2026-11-12 Revise verification and fabrication sections in README
    Updated section on verification and fabrication details, including PCBWay experience and verification checks.
